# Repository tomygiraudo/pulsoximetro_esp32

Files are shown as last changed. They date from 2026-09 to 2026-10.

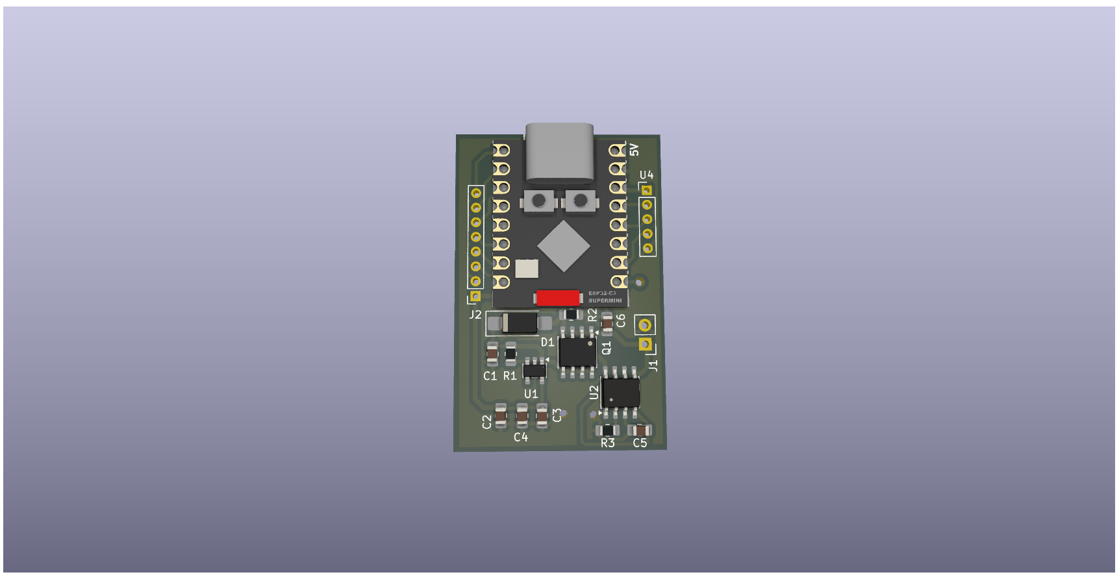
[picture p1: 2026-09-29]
PCB/Sensor_ctrl_pwr_pcb/Sensor_ctrl_pwr_pcb.png

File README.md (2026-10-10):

# Pulsoximetro portátil WI-FI

Diseño open-source de un pulsioxímetro doméstico portátil con conexión WI-FI para la materia de instrumentación Biomédica, realizado con un ESP32-C3 Super mini, un sensor de Fotoplestimografía (PPG) MAX30102, un circuito de carga y control de batería, una baterpia de 3.7 V y 230 mAh y una pantalla TFT 128x128 px con controlador STF775S.

Detalles:

- **Ciclo de medición:** el dashboard espera en "Listo para medir" hasta que el
  ESP32 manda el paquete de inicio (se presionó el botón de medición); recién
  entonces aparecen las lecturas, el cronómetro y la traza PPG.
- **Firmware** El firmware se encuentra en firmware/pulsox, tiene integrado todo lo hecho en los distintos tests de las otras carpetas.
- **Credenciales** Para que el pulsoxímetro se conecte a la aplicación y a la base de datos, se debe clonar el codigo de la base de datos y alojarlo en un proyecto firebase local. Por ultimo crear un archivo .env con las credenciales de la red wifi y las API's correspondientes para establecer la conexión con la base de datos.

## Procesamiento de Señal y diseño de filtros en Python
https://colab.research.google.com/drive/18P-XyyEuqM189sJWGMnf9TlH9UD-HeR_?usp=sharing 


Links utiles: 
https://www.analog.com/en/resources/reference-designs/maxrefdes117.html
https://www.analog.com/en/resources/technical-articles/how-to-design-a-better-pulse-oximeter.html 
https://www.analog.com/en/resources/technical-articles/guidelines-for-spo2-measurement--maxim-integrated.html

## Hardware
El esquemático del pulsioxímetro y todos sus componentes necesarios se detallan en PCB/Esquematico_V2.pdf/. Los archivos de diseño de la PCB se encuentran dentro de la misma carpeta. 



## Impresión de Carcasa
Los archivos STL para la impresión de la carcasa se encuentran en Carcasa/. Las partes fueron impresas en PETG para una mayor resistencia. 
**Parámetros de Impresión**
-  Altura de capa: 0,16 mm
-  Perímetros: 5 * 0,4 mm
-  Relleno: 50% o superior
Pulsoximetro_resorte_integrado v18
Pulsoximetro_resorte_integrado v18
Pulsoximetro_resorte_integrado v18

## Protocolo de telemetría

Ver [`PROTOCOL.md`](PROTOCOL.md): flujo de una medición (`hello` →
`measurement_start` → `telemetry` + `ppg` → fin) y formato de los mensajes JSON
que el firmware del ESP32 debe enviar por WebSocket, y el modelo de datos y las
llamadas REST del transporte en la nube. El armado de
`measurement_start`, `ppg` y `measurement_end` está marcado como **pendiente**.
El simulador (`web/js/simulator.js`) implementa el ciclo completo con un
formato provisional, así que sirve como referencia ejecutable además del
documento.

## Sistema de diseño y tipografías para pantalla y app web 

Ver [`design-system/pulsox-esp32/`](design-system/pulsox-esp32/): paleta,
tipografía, formas y especificación de componentes (gauge de SpO2, tarjeta de
frecuencia cardíaca, traza PPG, barra de navegación, historial) usados por la
web app.

 

  

## Próximos pasos

- Cerrar el armado de los paquetes pendientes de `PROTOCOL.md`
  (`measurement_start`, `ppg`, `measurement_end`).
- Firmware ESP32-C3: lectura del MAX30102, cálculo de SpO2/BPM integrado en el ESP32 C3.
- Cliente de la nube en el ESP32 (WiFi STA + TLS + login + keep-alive, integrado
  con deep sleep y el botón).
- Conectar la web app al dispositivo real y validar el modo `live` / Nube end-to-end.

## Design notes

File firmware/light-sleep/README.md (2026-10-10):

# light-sleep

Deja la placa en bajo consumo y ahí se queda. Al bootear, una sola vez:

1. **MAX30102**: corriente de los LEDs a 0 mA (`LED1_PA`/`LED2_PA` = 0) y bit
   `SHDN` en `MODE_CONFIG` (~1 µA). Se relee todo para confirmar que quedó así
   (hasta 3 intentos).
2. **ESP32-C3**: **light sleep** (`esp_light_sleep_start()`) **sin ninguna fuente
   de wakeup**, o sea indefinido. No es deep sleep: no hay timer ni botón que lo
   despierte.

El sketch nunca vuelve a encender el sensor. Como el MAX30102 se alimenta del riel
de 3V3 de la PCB (no del ESP32), queda en shutdown mientras la placa tenga
alimentación; solo se vuelve a encender si flasheás otro firmware que lo haga. Un
RESET no lo enciende: el sketch arranca de nuevo y lo vuelve a apagar.

El driver es el de [`firmware/pulsox/lib`](../pulsox/lib) (`lib_extra_dirs` en
`platformio.ini`), no una copia.

## Uso

```powershell
cd firmware/light-sleep
pio run -t upload
pio device monitor -p COM7
```

(`pio.exe` está en `%USERPROFILE%\.platformio\penv\Scripts`; el monitor sin `-p`
puede abrir un COM Bluetooth, mirá el puerto con `pio device list`.)

En el monitor tiene que salir:

```
=== light-sleep ===
MAX30102: LEDs a 0 mA y en shutdown (confirmado por lectura)
ESP32-C3: light sleep indefinido (sin fuente de wakeup). El USB se corta.
```

Si en vez de eso sale `NO se pudo apagar, err=...`, el MAX30102 no contestó por
I2C (revisar soldadura, SDA=GPIO3 / SCL=GPIO4). El ESP32 duerme igual.

## USB y volver a flashear

En light sleep el reloj del USB-Serial-JTAG del ESP32-C3 se apaga: después del
último mensaje la PC ve el puerto como desconectado y no se puede leer ni escribir
por Serial
([doc de Espressif](https://docs.espressif.com/projects/esp-idf/en/stable/esp32c3/api-guides/usb-serial-jtag-console.html)).
Por eso **para flashear otro firmware con la placa dormida** hay que:

1. Mantener apretado **BOOT** (GPIO9).
2. Tocar **RESET**.
3. Soltar BOOT y correr `pio run -t upload`.

Sin tocar BOOT: tras un RESET el puerto vive ~5 s (espera al monitor + 1,5 s) antes de
volver a dormir, que alcanza para un upload si lo lanzás en ese momento.

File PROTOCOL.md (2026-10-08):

# Protocolo de telemetría — PulsOx ESP32

Este documento define el formato de los paquetes que el firmware del ESP32-C3
debe enviar a la web app para que el dashboard funcione. Como todavía no existe
firmware, este formato es el contrato a implementar del lado del dispositivo.

> **Estado del documento.** El flujo de una medición y la semántica de cada
> paquete están definidos. El **armado de los paquetes nuevos**
> (`measurement_start`, `ppg` y `measurement_end`: campos, tipos, unidades,
> frecuencia) queda **PENDIENTE** — ver [Pendientes](#pendientes). Los paquetes
> `hello`, `telemetry` y `status` ya están cerrados.

## Transporte

**WebSocket**, con el ESP32 actuando como servidor en la red WiFi local.

```
ws://<ip-del-esp32>/ws
```

Se eligió WebSocket sobre BLE (Web Bluetooth) porque Web Bluetooth no funciona
en iOS/Safari, mientras que WebSocket sobre WiFi funciona en cualquier
navegador móvil moderno (Android e iOS) sin pairing previo. El ESP32 puede
operar en modo AP (crea su propia red `PulsOx-XXXX`) o en modo STA (se une a
la WiFi de casa) — el dashboard solo necesita la IP.

> **Transporte alternativo: la nube.** Un navegador bloquea `ws://` desde una
> página `https://` (contenido mixto), y el historial en `localStorage` no se
> comparte entre dispositivos. Por eso existe un segundo transporte en el que el
> ESP32 escribe en una Realtime Database de Firebase y la web la lee (ver
> [Transporte en la nube](#transporte-en-la-nube-firebase-realtime-database)).
> Los paquetes son los mismos y el WebSocket LAN sigue funcionando.

Todos los mensajes son JSON, un objeto por frame de texto. El campo `type`
identifica el tipo de mensaje.

## Ciclo de una medición

El dispositivo **no transmite lecturas mientras está en reposo**. Una medición
empieza cuando el usuario presiona el botón de medición del dispositivo:

```
ESP32                                                         Web app
  │  (el cliente abre la conexión)                               │
  │ ── hello ──────────────────────────────────────────────────► │  dashboard: "Listo para medir"
  │                                                              │
  │  (se presiona el botón de medición)                          │
  │ ── measurement_start ──────────────────────────────────────► │  abre la medición, arranca el cronómetro
  │ ── telemetry (≈ 1 Hz) ─────────────────────────────────────► │  SpO2, BPM, calidad, batería
  │ ── ppg (lotes de muestras) ────────────────────────────────► │  traza PPG en vivo
  │      …                                                       │
  │ ── measurement_end ────────────────────────────────────────► │  cierra la medición (ver pendientes)
```

- La web app asocia todas las lecturas recibidas entre `measurement_start` y el
  fin de la medición a **una misma medición**; el historial se agrupa así.
- `telemetry` y `ppg` solo se envían **dentro de** una medición.
- Si se cierra la conexión durante una medición, la web app la da por terminada.

## 1. `hello` — identificación del dispositivo

Se envía **una vez**, inmediatamente después de que el cliente abre la
conexión.

```json
{
  "type": "hello",
  "device_id": "pulsox-esp32-01",
  "fw_version": "0.1.0",
  "sensor": "MAX30102",
  "sample_rate_hz": 1
}
```

| Campo | Tipo | Descripción |
|---|---|---|
| `device_id` | string | Identificador único del dispositivo (p. ej. derivado de la MAC). |
| `fw_version` | string | Versión del firmware, para diagnóstico. |
| `sensor` | string | Sensor físico usado. |
| `sample_rate_hz` | number | Frecuencia aproximada de envío de `telemetry`. |

## 2. `measurement_start` — inicio de una medición

> **Estado: ⏳ PENDIENTE — armado del paquete a definir.**

Lo envía el ESP32 **una vez**, cuando se presiona el botón de medición. Es el
primer paquete de la medición: hasta que llega, la app muestra el dashboard en
espera ("Listo para medir", valores en "—", traza PPG vacía).

**Qué hace la app con este paquete:** abre una medición nueva (si había una
abierta, la cierra), pone el cronómetro en 00:00, limpia la traza PPG y crea el
grupo correspondiente en el historial.

**Supuesto provisional del cliente y del simulador** (no es el formato
definitivo): la app solo necesita el `type`. El identificador y la hora de
inicio de la medición los asigna ella misma al recibir el paquete; cualquier
otro campo se ignora. El simulador envía:

```json
{ "type": "measurement_start", "session_id": "sim-1700000000000", "uptime_ms": 5120 }
```

En el [transporte en la nube](#transporte-en-la-nube-firebase-realtime-database)
la web sintetiza este paquete con dos campos que la app **solo usa en ese
transporte**: `session_id` (la push key de `sessions/<sid>`, para que la medición
abierta coincida con el historial compartido) y `started_at` (ms epoch, para que
el cronómetro de quien se une a mitad de medición sea correcto).

## 3. `telemetry` — lectura periódica

El paquete de lecturas. Se espera aproximadamente **1 vez por segundo**, y solo
dentro de una medición (el algoritmo de SpO2/BPM del MAX30102 ya promedia
internamente sobre varios segundos de señal PPG).

```json
{
  "type": "telemetry",
  "seq": 4821,
  "uptime_ms": 182340,
  "finger_detected": true,
  "spo2": 97.4,
  "spo2_valid": true,
  "bpm": 72,
  "bpm_valid": true,
  "signal_quality": 0.86,
  "battery_pct": 78
}
```

| Campo | Tipo | Rango / notas |
|---|---|---|
| `seq` | integer | Contador incremental (detecta paquetes perdidos). |
| `uptime_ms` | integer | Milisegundos desde el boot del ESP32 (no hay RTC; el timestamp absoluto lo agrega el cliente al recibir). |
| `finger_detected` | boolean | `false` si el sensor no detecta dedo (IR por debajo de umbral). Si es `false`, `spo2`/`bpm` deben ignorarse aunque vengan presentes. |
| `spo2` | number \| null | Saturación de oxígeno en %, 0–100. `null` si no hay lectura válida. |
| `spo2_valid` | boolean | `true` solo si el algoritmo considera la lectura confiable (suficientes ciclos de pulso, sin saturación de señal). |
| `bpm` | number \| null | Frecuencia cardíaca en latidos por minuto. `null` si no hay lectura válida. |
| `bpm_valid` | boolean | Igual que `spo2_valid` pero para BPM. |
| `signal_quality` | number | 0.0–1.0, estimación de calidad de señal PPG (perfusion index normalizado o similar). Se usa para mostrar la barra de calidad de señal. |
| `battery_pct` | integer \| omitido | Opcional. Si el dispositivo no tiene medición de batería, se omite el campo por completo (no enviar `null`). |

Notas de diseño:
- Los campos `*_valid` existen porque el algoritmo de SpO2 del MAX30102 puede
  producir números incluso cuando la señal es mala; separarlos evita que el
  dashboard muestre un valor "creíble" que en realidad es ruido.
- El dashboard trata un paquete con `finger_detected: false` como "sin
  lectura": muestra "Colocá el dedo en el sensor", borra la traza PPG y no
  agrega el paquete al historial.
- Una lectura inválida aislada **no** borra el valor mostrado: la app conserva
  el último valor válido hasta 5 s (el gráfico de tendencia sí registra el
  corte).

## 4. `ppg` — señal PPG

> **Estado: ⏳ PENDIENTE — armado del paquete a definir.**

Transporta la señal fotopletismográfica **ya filtrada y acondicionada** por el
firmware, para dibujarla en vivo en el dashboard debajo de la frecuencia
cardíaca. La app **no filtra ni procesa**: solo la dibuja.

**Qué necesita la app de este paquete:**
- Muestras numéricas en orden temporal, con polaridad tal que el **pico
  sistólico apunte hacia arriba**. La escala es libre: la app autoescala el eje
  vertical, así que no hace falta normalizar ni mandar unidades.
- La frecuencia de muestreo, para ubicar cada muestra en el eje de tiempo.
- Las muestras llegan **en lotes** (un frame = varias muestras): mandar una
  muestra por frame a decenas de Hz satura el servidor WebSocket del ESP32-C3.

**Qué hace la app:** mantiene una ventana deslizante de 6 s, dibujada con un
retardo de ~0,3 s respecto de "ahora" para que los lotes se rellenen de forma
fluida. Mientras no hay dedo (según `telemetry`), no dibuja la traza.

**Supuesto provisional del cliente y del simulador** (no es el formato
definitivo): `fs` en Hz y `samples` como arreglo de números; el simulador usa
`fs = 50` y manda 10 muestras cada 200 ms.

```json
{ "type": "ppg", "fs": 50, "samples": [112, 340, 655, 801, 742, 590, 331, 40, -120, -210] }
```

## 5. `measurement_end` — fin de una medición

> **Estado: ⏳ PENDIENTE — falta decidir si existe como paquete y su armado.**

Marcaría el fin de la medición (el usuario la detiene o el firmware la corta por
duración máxima). Al recibirlo la app cierra la medición, deja de mostrar
lecturas y vuelve a "Listo para medir"; el grupo del historial queda con su
duración.

**Supuesto provisional del cliente y del simulador:** la app solo necesita el
`type`. El simulador envía `{ "type": "measurement_end", "uptime_ms": 65210 }`.

## 6. `status` — eventos y errores

Mensaje esporádico para comunicar cambios de estado que no son una lectura.

```json
{
  "type": "status",
  "level": "error",
  "code": "sensor_not_found",
  "message": "No se detecta el MAX30102 en el bus I2C"
}
```

| Campo | Tipo | Valores |
|---|---|---|
| `level` | string | `"info"` \| `"warning"` \| `"error"` |
| `code` | string | Código estable para lógica del cliente (`sensor_not_found`, `low_battery`, `wifi_reconnected`, etc.). |
| `message` | string | Texto legible, se muestra tal cual en la UI como fallback. |

## Convenciones generales

- Codificación: JSON UTF-8 en frames de texto WebSocket (no binario).
- El servidor (ESP32) puede cerrar y reabrir la conexión libremente; el
  cliente reintenta con backoff exponencial (ver `web/js/connection.js`).
- No se espera que el cliente envíe telemetría al servidor; el canal es
  unidireccional (ESP32 → navegador). Un futuro `ping`/`pong` de aplicación no
  es necesario porque el protocolo WebSocket ya tiene ping/pong nativo.
- Todos los valores numéricos van sin comillas (JSON number), nunca como
  string.
- Un `type` desconocido se descarta sin error (compatibilidad hacia adelante).

## Umbrales fisiológicos usados por el dashboard

Estos umbrales son los que la web app usa por defecto para colorear el
estado (verde / amarillo / rojo). Son guías generales de bienestar, **no**
un dispositivo médico certificado, y son configurables desde Ajustes
(se guardan en `localStorage`, no se envían al ESP32).

| Parámetro | Verde (normal) | Amarillo (precaución) | Rojo (peligro) |
|---|---|---|---|
| SpO2 | ≥ 95% | 90–94% | < 90% |
| BPM (reposo) | 60–100 | 50–59 o 101–120 | < 50 o > 120 |

## Ejemplo de sesión

Los paquetes marcados con ⏳ tienen el armado pendiente; se muestran con el
supuesto provisional del cliente.

```
→ (cliente abre ws://192.168.1.42/ws)
← {"type":"hello","device_id":"pulsox-esp32-01","fw_version":"0.1.0","sensor":"MAX30102","sample_rate_hz":1}
      … (reposo: el dashboard muestra "Listo para medir") …
      … (se presiona el botón de medición) …
← ⏳ {"type":"measurement_start"}
← {"type":"telemetry","seq":1,"uptime_ms":1000,"finger_detected":false,"spo2":null,"spo2_valid":false,"bpm":null,"bpm_valid":false,"signal_quality":0.0}
← {"type":"telemetry","seq":2,"uptime_ms":2000,"finger_detected":true,"spo2":96.8,"spo2_valid":false,"bpm":81,"bpm_valid":false,"signal_quality":0.31}
← ⏳ {"type":"ppg","fs":50,"samples":[…10 muestras…]}
← {"type":"telemetry","seq":3,"uptime_ms":3000,"finger_detected":true,"spo2":97.2,"spo2_valid":true,"bpm":74,"bpm_valid":true,"signal_quality":0.79}
← ⏳ {"type":"ppg","fs":50,"samples":[…10 muestras…]}
      …
← ⏳ {"type":"measurement_end"}
```

## Implementación de referencia (cliente)

El parseo y la validación de estos mensajes están en
[`web/js/protocol.js`](web/js/protocol.js); la traza PPG se dibuja en
[`web/js/ppg.js`](web/js/ppg.js). El simulador de demo en
[`web/js/simulator.js`](web/js/simulator.js) genera el ciclo completo
(`hello` → `measurement_start` → `telemetry` + `ppg` → `measurement_end`), así
que sirve como referencia ejecutable además de este documento. El cliente es
**permisivo** con los paquetes pendientes (solo exige el `type` y, para `ppg`,
el arreglo numérico `samples`), de modo que el armado definitivo se puede
decidir sin romper la app.

Si llegan `telemetry` o `ppg` sin un `measurement_start` previo (p. ej. el
cliente se reconecta con una medición en curso), la app abre una medición
implícita en lugar de descartar los datos.

## Transporte en la nube (Firebase Realtime Database)

Segundo transporte, para que **cualquiera con la URL de la web** vea la medición
en vivo y el historial desde cualquier red, sin conocer la IP del ESP32 ni estar
en su WiFi. GitHub Pages es hosting estático (no guarda datos ni acepta
conexiones) y el ESP32 no puede ser cliente de la *página*; lo que sí se puede es
que **los dos sean clientes del mismo servicio en la nube**:

```
ESP32 ──HTTPS (REST, con login)──►  Firebase Realtime DB  ◄──REST + streaming (EventSource), lectura pública──  Web (Pages, cualquier celular/PC)
```

- **Solo el dispositivo escribe.** La lectura es pública (sin login); la
  escritura la permite únicamente el `uid` del usuario del dispositivo
  ([`tools/cloud/database.rules.json`](tools/cloud/database.rules.json)).
- **La medición se inicia solo con el botón del dispositivo**; la app no manda
  comandos. Por eso el ESP32 puede dormir en deep sleep entre mediciones: no
  tiene que estar escuchando.
- Se guardan **valores crudos**. El estado (normal / precaución / peligro) lo
  calcula cada cliente con *sus* umbrales.
- Las horas son del servidor (`{".sv":"timestamp"}`, abreviado `SV` abajo): el
  ESP32 no tiene RTC ni necesita NTP.
- Los paquetes que entiende la app son los mismos de las secciones 1–6; este
  transporte solo cambia cómo viajan (ver [cómo lo interpreta la web](#cómo-lo-interpreta-la-web)).

### Nodos

```
/devices/<deviceId>/
  info      { device_id, fw_version, sensor, battery_pct, updated }      al arrancar y al terminar cada medición
  live      { session_id, seq, ts, elapsed_ms, finger_detected, spo2,    PUT a 1 Hz solo durante la medición;
              spo2_valid, bpm, bpm_valid, signal_quality, battery_pct,   se borra al terminar
              fs, ppg:"112,340,…" }
  sessions/<sid>  { startedAt, endedAt, readings/<pushKey> { ts, spo2, bpm, quality } }
                                                                          sid = push key (orden cronológico);
                                                                          readings: POST cada ~5 s con lectura válida
```

`<deviceId>` es la "llave" de la URL de lectura (`web/js/cloud-config.js` y
`PULSOX_DEVICE_ID`): un valor no obvio y sin datos personales.

**`live`** (se reemplaza completo con `PUT` cada segundo; la base no guarda
`null`, así que un campo sin valor **se omite**):

| Campo | Tipo | Notas |
|---|---|---|
| `session_id` | string | Push key de la sesión (`sessions/<sid>`). |
| `seq` | integer | Contador de la medición (1, 2, 3…). Cada `seq` nuevo es un "tick" para la web. |
| `ts` | number | `SV`. |
| `elapsed_ms` | integer | Milisegundos desde que se presionó el botón, medidos por el dispositivo. La web calcula con esto el inicio de la medición (quien entra a mitad ve el cronómetro correcto sin fiarse de relojes). |
| `finger_detected` | boolean | Igual que en `telemetry`. |
| `spo2`, `bpm` | number | Solo si hay dedo; ver `telemetry`. |
| `spo2_valid`, `bpm_valid` | boolean | Igual que en `telemetry`. |
| `signal_quality` | number | 0.0–1.0. |
| `battery_pct` | integer | Se omite si no se mide. |
| `fs` | integer | Frecuencia de muestreo del PPG en Hz. |
| `ppg` | string | `fs` muestras enteras (1 s de señal) separadas por comas, ya filtradas, pico sistólico hacia arriba. Se omite sin dedo. Una hoja atómica (~250 B a 50 Hz) en vez de un arreglo, y un solo request por segundo con la telemetría incluida. |

**`info`**: `device_id`, `fw_version`, `sensor` (strings, como en `hello`),
`battery_pct` (se actualiza al terminar cada medición: es la batería "en
reposo") y `updated` (`SV`).

**`sessions/<sid>`**: `startedAt` (`SV`, lo escribe el `POST` que abre la
medición), `endedAt` (`SV`, al terminar) y `readings/<pushKey>` con
`{ ts (SV), spo2, bpm, quality }` cada ~5 s mientras haya lectura válida.

### Llamadas REST del dispositivo

`<db>` es el `databaseURL` (`https://<proyecto>-default-rtdb.firebaseio.com`) y
`<auth>` el `idToken` del usuario del dispositivo (`?auth=<idToken>`). Las
escrituras que no necesitan respuesta llevan `&print=silent` (la base contesta
`204 No Content`).

| # | Cuándo | Llamada | Cuerpo | Respuesta |
|---|---|---|---|---|
| 1 | Al arrancar | `POST https://identitytoolkit.googleapis.com/v1/accounts:signInWithPassword?key=<API_KEY>` | `{"email","password","returnSecureToken":true}` | `idToken`, `refreshToken`, `expiresIn: "3600"`, `localId` |
| 2 | Antes de que venza el token | `POST https://securetoken.googleapis.com/v1/token?key=<API_KEY>` | formulario `grant_type=refresh_token&refresh_token=…` | `id_token`, `refresh_token`, `expires_in: "3600"` |
| 3 | Al arrancar | `PUT <db>/devices/<id>/info.json?auth=<auth>` | `info` completo | — |
| 4 | Al arrancar | `DELETE <db>/devices/<id>/live.json?auth=<auth>` | — | — |
| 5 | Botón de medición | `POST <db>/devices/<id>/sessions.json?auth=<auth>` | `{"startedAt": SV}` | `{"name": "<sid>"}` |
| 6 | Cada segundo | `PUT <db>/devices/<id>/live.json?auth=<auth>` | `live` completo | — |
| 7 | Cada ~5 s (lectura válida) | `POST <db>/devices/<id>/sessions/<sid>/readings.json?auth=<auth>` | `{"ts": SV, "spo2", "bpm", "quality"}` | `{"name": …}` |
| 8 | Al terminar | `PATCH <db>/devices/<id>/sessions/<sid>.json?auth=<auth>` | `{"endedAt": SV}` | — |
| 9 | Al terminar | `PATCH <db>/devices/<id>/info.json?auth=<auth>` | `{"battery_pct", "updated": SV}` | — |
| 10 | Al terminar | `DELETE <db>/devices/<id>/live.json?auth=<auth>` | — | — |

Notas para el firmware (la especificación ejecutable es
[`tools/cloud/fake_device.py`](tools/cloud/fake_device.py)):

- **Orden de cierre: 8, 9 y 10 al final.** Borrar `live` es la señal de
  "medición terminada" para los visores; si va antes, el historial que refrescan
  podría no tener todavía `endedAt`.
- **Conexión persistente.** Un handshake TLS por cada PUT de 1 Hz costaría
  ~1 s: mantener una sola conexión HTTPS abierta (keep-alive;
  `HTTPClient::setReuse(true)` en el ESP32) y reabrirla si el servidor la cierra.
- **Token.** Vence a la hora (`expiresIn: 3600`). Renovarlo con margen (p. ej. a
  los 50 min con la llamada 2); ante un `401` hacer un login nuevo (llamada 1) y
  reintentar una vez. Un `401` también lo devuelve una regla incumplida
  (`.validate`, escritura de otro usuario): la API REST responde `401
  Permission denied` ante cualquier violación de reglas.
- **Fallos de red.** Un tick que no se pudo escribir se descarta (el siguiente
  llega en 1 s); no acumular una cola. El historial se arma con las lecturas de
  la llamada 7, que no necesitan 1 Hz.
- **Arranque y deep sleep.** Al arrancar: llamadas 3 y 4 (4 limpia el `live` que
  deja un corte de energía a mitad de medición). Antes de dormir, la medición
  tiene que estar cerrada (8–10).
- **Credenciales.** Email/contraseña y API key van en un archivo que no se
  versiona (en el firmware, un header ignorado por git; en las herramientas,
  `tools/cloud/.env`). La API key web de Firebase identifica al proyecto, no
  autoriza nada por sí sola.
- **Certificado.** Validar el certificado TLS contra la CA raíz que usan los
  servidores de Google (verificarla desde el navegador antes de fijarla en el
  firmware) en lugar de `setInsecure()`.
- **Volumen.** Un PUT de `live` ronda los 0,5–0,6 KB: una medición de 1 h son
  ~2 MB de subida más ~720 lecturas de ~70 B.

### Cómo lo interpreta la web

`web/js/cloud.js` (`CloudSource`) abre un `EventSource` a
`<db>/devices/<id>/live.json` (la base manda `put` / `patch` con `{path, data}`
y un `keep-alive` cada ~30 s; si antepone un `307`, el navegador lo sigue solo),
mantiene una copia local de `live` y **sintetiza los mismos frames del
WebSocket**, de modo que `app.js` no distingue el transporte:

| Cambio en la base | Frame que recibe la app |
|---|---|
| `GET info.json` al abrir y al terminar cada medición | `hello` (`device_id`, `fw_version`, `sensor`, `sample_rate_hz: 1` y, si hay, `battery_pct`: la batería en reposo) |
| Aparece `live` o cambia su `session_id` | `measurement_start` con `session_id` y `started_at` (ms epoch = hora local de recepción − `elapsed_ms`; son los dos campos que la app usa de este paquete solo en este transporte) |
| Cada `seq` nuevo | `telemetry` y, si hay `ppg`, `ppg` (`fs` y `samples`, en ese orden) |
| `live` se borra | `measurement_end` |
| ~10 s sin un `seq` nuevo con la medición abierta | `measurement_end` (dispositivo apagado o sin WiFi a mitad); si vuelve a escribir, la medición se reabre |

Más detalles del comportamiento:

- Un `live` que ya está en la base al conectar **no se cree hasta que cambia**
  (llega otro `seq` en 3 s): si el dispositivo perdió energía a mitad de una
  medición, ese nodo queda para siempre y no debe mostrarse como una medición en
  curso. Un `live` que aparece con el stream abierto arranca sin espera.
- Sin ningún evento (ni `keep-alive`) durante 65 s se reabre el stream; ante
  `cancel` / `auth_revoked` o un error HTTP se reintenta con backoff
  (1 s … 15 s); al volver a la pestaña (`visibilitychange`; iOS corta las
  conexiones en segundo plano) se reabre y se re-sincroniza.
- Las muestras PPG llegan en lotes de 1 s: la traza se dibuja con ~1,5 s de
  demora respecto del dedo (300 ms en el transporte LAN). La pantalla TFT del
  dispositivo es inmediata.
- **Historial** (`CloudHistory`): `GET <db>/devices/<id>/sessions.json?orderBy="startedAt"&limitToLast=30`
  (requiere el `.indexOn` de las reglas). Recalcula el estado con los umbrales del
  visor y aplica el mismo adelgazado que el historial local (primera lectura,
  cada cambio de estado y una cada 20 s). Una sesión sin `endedAt` que no es la
  que se está midiendo se muestra terminada en su última lectura (no "En curso").
  Se refresca al abrir Historial, al terminar una medición y cada 10 s mientras
  haya una medición abierta con el Historial a la vista. Es de solo lectura:
  "Borrar historial" se deshabilita en esta fuente.
- La app que se sirve desde GitHub Pages (HTTPS) puede usar este transporte
  porque `fetch` / `EventSource` hacia la base también son HTTPS; el WebSocket
  LAN (`ws://`) queda bloqueado por el navegador en una página HTTPS.

### Límites y privacidad

- **Datos de salud en un servicio de lectura pública.** Para un trabajo práctico
  alcanza con un `deviceId` no obvio y sin datos personales; **no sirve como
  producto** (sin autenticación de lectores, sin borrado por el usuario).
- Plan sin costo de Firebase: 100 conexiones simultáneas (cada visor abierto es
  una) y cuotas de almacenamiento y descarga; el volumen por medición es de
  KB, pero conviene mirar el uso en la consola.
- Las reglas se verifican contra el servicio real con
  [`tools/cloud/check_rules.py`](tools/cloud/check_rules.py).

## Pendientes

Armado de los paquetes y decisiones asociadas, a cerrar junto con el firmware:

- [ ] **`measurement_start`**: campos (identificador de medición, base de
      `uptime_ms`, configuración del sensor, batería inicial, etc.).
- [ ] **`ppg`**: campos y tipos (`fs`, `seq`, `samples` como entero o float,
      timestamp/`uptime_ms` del primer sample), tamaño de lote y periodo de
      envío, polaridad y escala de la señal ya acondicionada, y verificar que el
      servidor WebSocket del ESP32-C3 sostiene el caudal.
- [ ] **Frecuencia de muestreo** de la señal PPG que se transmite (puede ser
      menor que la del ADC del MAX30102).
- [ ] **`measurement_end`**: ¿existe como paquete?, ¿lo manda el firmware al
      soltar el botón / por duración máxima / por inactividad?, ¿con motivo y
      resumen?
- [ ] **Botón presionado durante una medición**: ¿la detiene o la reinicia?
- [ ] **Sin dedo**: confirmar que durante `finger_detected: false` el firmware
      no envía `ppg` (hoy la app lo ignora después de la primera `telemetry`).
- [ ] **Reconexión a mitad de medición**: ¿`hello` informa si hay una medición
      en curso (y hace cuánto empezó) para no depender de la medición
      implícita?
- [ ] **Batería** fuera de una medición: por WebSocket hoy solo viaja en
      `telemetry`; ¿se agrega a `hello`/`measurement_start` para mostrarla en
      reposo? (En la nube ya está resuelto: `info.battery_pct`, que la web
      entrega como `hello.battery_pct`; la app lo acepta en cualquier `hello`.)
- [ ] **Cliente del ESP32 para la nube** (plan aparte): WiFi STA + TLS + login +
      keep-alive, y su integración con deep sleep y el botón (GPIO0); sigue
      [`tools/cloud/fake_device.py`](tools/cloud/fake_device.py).

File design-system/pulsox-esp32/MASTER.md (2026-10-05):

# Design System — PulsOx ESP32

> **LOGIC:** When building a specific screen, first check
> `design-system/pulsox-esp32/pages/[page-name].md`. If that file exists, its
> rules **override** this Master file. If not, follow the rules below.
>
> Rediseño "consumer wearable" (sucede al sistema teal/clínico anterior). Los
> tokens vivos están en `web/css/tokens.css`; este documento es la referencia
> de diseño detrás de ellos.

**Project:** PulsOx ESP32
**Dirección:** wearable de consumo (Apple Watch / Fitbit / Whoop): cálido,
legible, redondeado. **No** estética clínica/hospitalaria.
**Tema por defecto:** claro (día). Oscuro (noche) y Auto como opciones.

---

## Color

Dos colores de marca, cada uno ligado a una magnitud. Verde / ámbar / rojo
quedan **reservados para el estado fisiológico** y nunca se usan como decoración.

| Rol | Claro | Oscuro | Token |
|---|---|---|---|
| Fondo | `#F4F2EF` | `#0C0D12` | `--color-background` |
| Superficie (tarjetas, nav) | `#FFFFFF` | `#16181F` | `--color-surface` |
| Superficie 2 (controles) | `#ECE9E4` | `#22252F` | `--color-surface-2` |
| Pista (gauge, barras) | `#E6E3DE` | `#2A2D3A` | `--color-track` |
| Texto | `#16151D` | `#F5F4F8` | `--color-foreground` |
| Texto secundario | `#5B5A6B` | `#9EA0B4` | `--color-muted` |
| **SpO₂ / marca** (azul) | `#2B58E0` | `#6B97FF` | `--color-primary` |
| **Frecuencia / PPG** (violeta) | `#6A44D8` | `#B39BFF` | `--color-violet` |
| Destructivo | `#B93030` | `#E35B5B` | `--color-destructive` |

Contraste: texto secundario ≥ 4,5:1 sobre fondo y superficie en ambos temas; el
azul y el violeta de marca ≥ 4,5:1 sobre su superficie.

### Estado (fijo, validado, nunca tematizado)

| Estado | Valor | Token |
|---|---|---|
| Normal | `#0CA30C` | `--color-status-good` |
| Precaución | `#FAB219` | `--color-status-warning` |
| Peligro | `#D03B3B` claro / `#E35B5B` oscuro | `--color-status-critical` |

**Regla:** el estado nunca va solo en color. Siempre lleva ícono (check /
triángulo / octógono) **y** texto ("Normal" / "Precaución" / "Peligro"). El
ámbar tiene bajo contraste sobre claro, así que se usa como tinte de fondo o
color de ícono/anillo, y el texto del pill va en `--color-foreground`. Cada
estado trae un `tint` (fondo de pills y de íconos) y un `glow` (halo del anillo).

## Tipografía

**Figtree** (pesos 500 / 600 / 700 / 800) para todo. Cifras con
`font-variant-numeric: tabular-nums`.

| Uso | Tamaño / peso |
|---|---|
| Valor SpO₂ (anillo) | 66 px / 800 |
| Valor frecuencia | 52 px / 800 |
| Titular de pantalla (h1 de vista) | 30 px / 800 |
| Titular de estado (dashboard) | 26 px / 800 |
| Título de tarjeta | 16 px / 700 |
| Cuerpo / subtítulo | 14 px / 500 |
| Etiquetas, pills, controles | 12–14 px / 600–700 |

Un valor sin dato se muestra como guion "—" en `--color-muted`, peso 500 (nunca
en negrita: el guion pesado se lee como una barra).

## Forma y espaciado

- Radios: tarjetas 28 px (lista de historial 24 px), controles 16 px, botones
  grandes 18 px, **pills 999 px**.
- Espaciado entre bloques 12 px (24 px entre secciones); columna única de
  máx. 520 px con gutter de 20 px.
- Sin sombras en tarjetas: la jerarquía sale del contraste fondo/superficie. La
  única sombra es la del toast.

## Componentes

- **Pill de estado:** ícono + etiqueta, fondo = `tint` del estado, texto en
  `--color-foreground`.
- **Segmented control:** pista `--color-surface-2`, opción activa en
  `--color-primary` (selector de magnitud, tema) o en tinta (rango de tiempo).
- **Chips de filtro:** pill; activo en tinta (`--color-foreground`).
- **Switch:** 52 × 32 px, activo en `--color-primary`.
- **Campos:** 52 px de alto, fondo `--color-surface-2`, anillo de foco en
  `--color-primary`.
- **Barra de navegación inferior:** ver `pages/dashboard.md`.

## Movimiento

Transiciones de 150–400 ms con `cubic-bezier(0.4, 0, 0.2, 1)` (el gauge anima
su arco en 400 ms). `prefers-reduced-motion` desactiva transiciones y
animaciones decorativas; la traza PPG sigue desplazándose porque *es* el dato.

## Anti-patrones

- ❌ Emojis como íconos (usar SVG de trazo).
- ❌ Estado transmitido solo por color.
- ❌ Usar verde / ámbar / rojo como color decorativo o de marca.
- ❌ Animación tipo contador/odómetro en el valor principal (un signo vital en
  vivo no "carga" hasta su valor).
- ❌ Borrar o truncar el historial sin una acción explícita del usuario.
- ❌ Bloquear la UI o mostrar un spinner al reconectar: se mantiene la última
  lectura y el estado de conexión refleja el corte.
- ❌ Eje doble combinando SpO₂ y frecuencia en un mismo gráfico.
- ❌ Botones y campos de acción principal menores a 44 px (los chips y segmentados
  compactos miden 32–40 px y van siempre separados entre sí).

## Checklist previo a entregar

- [ ] Sin emojis; íconos de un mismo set de trazo
- [ ] `cursor: pointer` en todo lo clicable; foco visible (`:focus-visible`)
- [ ] Contraste de texto ≥ 4,5:1 en claro y oscuro
- [ ] `prefers-reduced-motion` respetado
- [ ] Sin scroll horizontal a 360 px, 390 px y escritorio
- [ ] Nada tapado por la barra de navegación fija (padding inferior + safe-area)
- [ ] Estados cubiertos: sin conexión, esperando medición, midiendo, sin dedo,
      calibrando, precaución, peligro

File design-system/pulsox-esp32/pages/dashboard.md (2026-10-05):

# Pantallas — Override de `MASTER.md`

> Especificación de las tres vistas de la app (Historial · Dashboard ·
> Ajustes) y de la barra de navegación. Prevalece sobre `MASTER.md` en lo que
> contradiga. Tokens, tipografía, formas y anti-patrones de Master siguen
> vigentes.

## Navegación inferior

Barra fija abajo, ancho de la columna (máx. 520 px), con tres destinos en este
orden: **Historial · Dashboard · Ajustes** (el dashboard al centro, vista por
defecto).

- Rutas por hash: `#/history`, `#/dashboard`, `#/settings`.
- Cada destino es un `<a>` de ≥ 56 px de alto con ícono (22 px) sobre etiqueta
  (12 px). El activo lleva `aria-current="page"`, ícono en `--color-primary`
  sobre una cápsula `--color-primary-tint` de 60 × 32 px, y etiqueta en negrita
  color `--color-foreground`; los inactivos van en `--color-muted`.
- Fondo `--color-surface`, filete superior `--color-line`, padding inferior con
  `env(safe-area-inset-bottom)`. El contenido reserva ese alto para que nada
  quede tapado.
- Al cambiar de vista: scroll arriba, `document.title` = "PulsOx — <vista>" y el
  foco pasa al `h1` de la vista.

## Dashboard

Entra en una sola pantalla de 390 × 844 (sin scroll), de arriba abajo:

1. **Cabecera:** marca "PulsOx" a la izquierda; a la derecha el pill de conexión
   (`En vivo` / `Conectado` / `Demo` / `Reconectando…` / `Sin conexión`, siempre
   con punto + texto) y el chip de batería (solo si el dispositivo la informa;
   `< 20 %` → ícono ámbar y "· baja").
2. **Titular de estado** (h1, 26 px) con ícono de estado, y una línea de apoyo.
   Es lenguaje natural, no una etiqueta:

   | Situación | Titular |
   |---|---|
   | Sin conexión / conectando | "Sin conexión" / "Conectando…" |
   | Conectado, sin medición | "Listo para medir" — "Presioná el botón de medición del dispositivo para empezar." |
   | Midiendo, sin dedo | "Esperando lectura" |
   | Midiendo, señal sin estabilizar | "Calibrando…" |
   | Midiendo, todo normal | "Todo en rango" |
   | Midiendo, algún valor en precaución | "Fuera del rango habitual" |
   | Midiendo, algún valor en peligro | "Valores críticos" + motivo + "Si te sentís mal, buscá atención médica." |

   Durante la medición la línea de apoyo lleva el cronómetro ("Midiendo · 00:23").
3. **Tarjeta SpO₂:** gauge de anillo abierto (270°, escala fija 80–100 %) con el
   valor en 66 px al centro y el pill de estado en el hueco inferior. El arco
   toma el color del estado, con halo suave; la pista queda en `--color-track`.
   Dos muescas marcan los umbrales de "Precaución" y "Normal" (siguen a los
   umbrales configurados).
4. **Tarjeta frecuencia cardíaca:** valor en 52 px + "lpm" y, a la derecha, el
   pill de estado.
5. **Tarjeta Señal PPG:** título + etiqueta "Filtrada" y, a la derecha, la
   calidad de señal en cinco barras (solo con dedo). Debajo, la traza en vivo:

   - Ventana de 6 s, dibujada en canvas; una línea punteada por segundo, línea
     base y rótulos "−6 s" / "ahora".
   - Trazo violeta (`--color-violet`) que se desvanece hacia la izquierda y
     alcanza su máxima intensidad en el borde vivo, con un punto en la muestra
     más reciente y un relleno suave debajo.
   - Eje vertical autoescalado y suavizado (sin unidades): la señal ya llega
     filtrada y con el pico sistólico hacia arriba.
   - Sin señal (en espera, sin dedo, sin conexión) la traza se reemplaza por una
     línea punteada y un mensaje centrado.

**Estados del valor:** sin dato → guion "—" en `--color-muted`; lectura inválida
aislada → se conserva el último valor válido hasta 5 s ("mostrar el último
estado conocido, no vaciar la pantalla"); el pill dice "Calibrando…" si pasan
más de 5 s sin lectura válida.

**Modo demo:** debajo del titular aparece un botón suave "Simular botón de
medición" / "Detener medición (demo)". En producción no existe: la medición la
inicia el botón físico del dispositivo.

## Historial

- Cabecera: h1 "Historial" y a la derecha el conteo de mediciones.
- **Tarjeta de tendencia:** segmented "SpO₂ | Frecuencia" (una magnitud por vez,
  nunca dos ejes), gráfico de línea con área degradada, bandas de zona
  (rojo / ámbar / verde según umbrales) y punto final; ticks del eje Y en los
  umbrales y cinco rótulos de tiempo repartidos por igual. Debajo, segmented de
  rango "2 min | 10 min | 1 h" en tinta.
- **Lecturas:** título de sección, chips `Todas | Precaución | Peligro` y una
  lista **agrupada por medición**. Cada grupo lleva "Hoy · 14:32" y "Medición
  de 1 min 20 s" ("En curso" si sigue abierta). Cada fila: ícono de estado en
  cuadrado tintado (40 px), "97 % SpO₂ · 72 lpm", la etiqueta del estado y la
  hora (HH:MM:SS) a la derecha. El historial anterior al agrupamiento aparece
  como "Lecturas anteriores".
- Vacío: ícono + "Todavía no hay mediciones. Iniciá una desde el dashboard." (o
  "No hay lecturas con este filtro.").

## Ajustes

Grupos en tarjetas con título en mayúsculas pequeñas: **Conexión** (dirección
WebSocket, botón "Conectar", switch "Modo demo", datos del dispositivo),
**Apariencia** (segmented **Claro** | Oscuro | Auto; Claro es el predeterminado),
**Umbrales de SpO₂**, **Umbrales de frecuencia** (campos numéricos de 52 px en
grilla de 2 columnas; sin sliders: en una lectura de salud importa la
precisión), **Historial** ("Borrar historial", destructivo, con confirmación en
un segundo toque) y el aviso de que la app no es un dispositivo médico.

## Anti-patrones específicos de estas pantallas

- ❌ Mostrar lecturas o traza PPG antes de recibir el paquete de inicio.
- ❌ Dibujar la traza PPG con el dedo fuera del sensor.
- ❌ Procesar o filtrar la señal PPG en el cliente (llega acondicionada).
- ❌ Un eje doble SpO₂ + frecuencia.
- ❌ Estado por color solo (siempre ícono + texto).
- ❌ Vaciar el valor por una única lectura inválida.

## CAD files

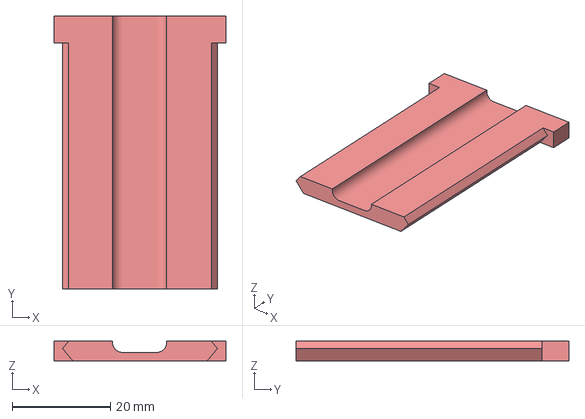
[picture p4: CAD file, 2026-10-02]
Carcasa/Tapa inferiOR.3mf
35.0 x 55.5 x 4.00 mm

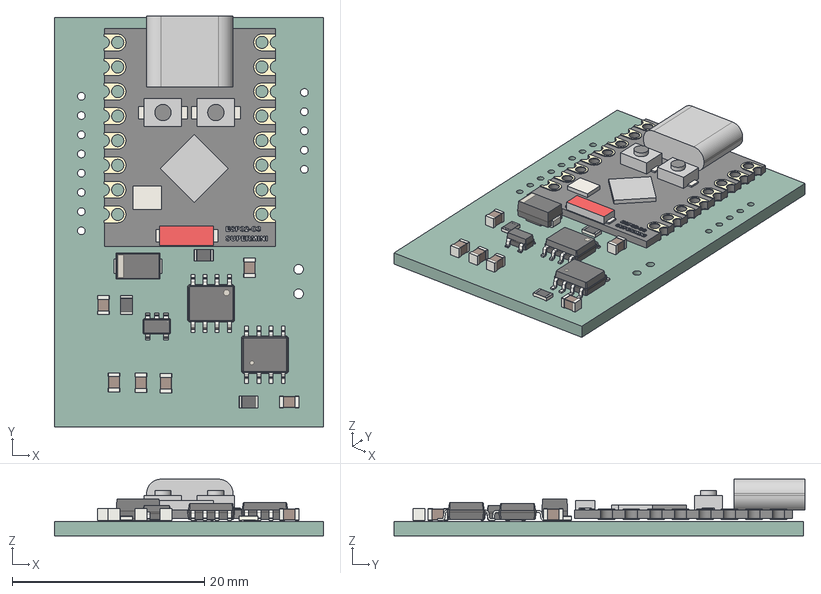
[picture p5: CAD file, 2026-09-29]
PCB/Sensor_ctrl_pwr_pcb/Sensor_ctrl_pwr_pcb.step
28.0 x 42.8 x 5.90 mm
R_0805_2012Metric x 3
SOIC-8_3.9x4.9mm_P1.27mm
C_0805_2012Metric x 6
SO-8_3.9x4.9mm_P1.27mm
SOT-23-5
D_SMA
Sensor_ctrl_pwr_pcb_PCB

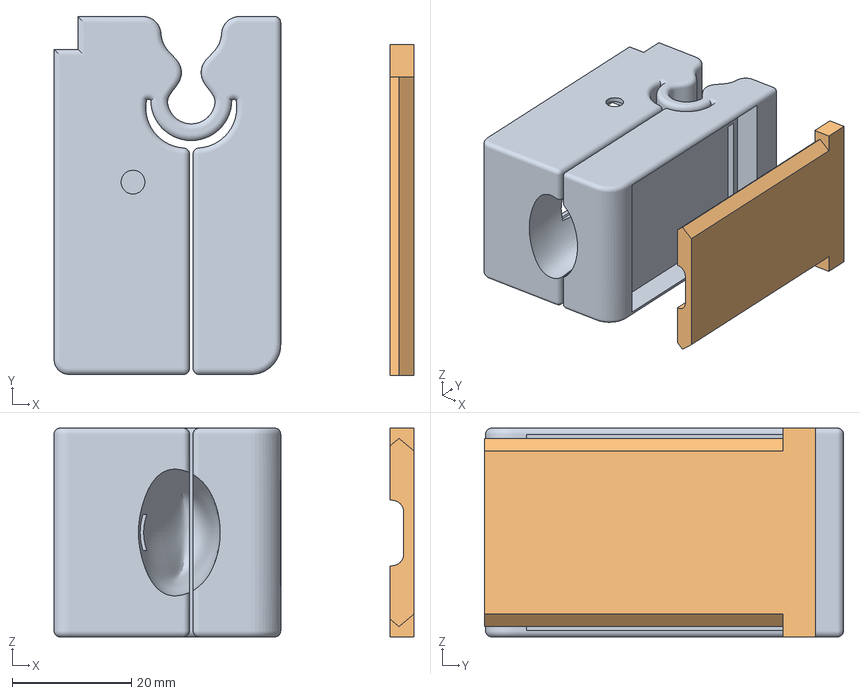
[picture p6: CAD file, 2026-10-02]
Carcasa/Pulso oxímetro.3mf
60.3 x 60.2 x 35.0 mm
Pulso oxímetro
Tapa inferiOR

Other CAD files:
PCB/Sensor_ctrl_pwr_pcb/Sensor_ctrl_pwr_pcb.obj
PCB/Sensor_ctrl_pwr_pcb/Sensor_ctrl_pwr_pcb.stl

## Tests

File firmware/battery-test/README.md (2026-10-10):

# Battery autonomy test

Sketch de prueba para el ESP32-C3 Super Mini. Un solo ciclo, en este orden:

1. **Self-test del MAX30102** (antes del WiFi): reset, prende los LEDs en modo
   SpO2, lee un par de muestras (RED/IR, válidas = distintas de 0), apaga los
   LEDs y lo deja en **shutdown** de bajo consumo. Imprime `PASS` o `FAIL`.
2. **WiFi**: conecta y manda paquetes UDP ("hello world" + su propia IP)
   durante unos segundos.
3. `deep sleep` **para siempre** (sin timer de wakeup — solo despierta de
   nuevo con un reset manual o power cycle).

El MAX30102 sigue alimentado desde el riel de 3V3 aunque el ESP32 se resetee o
esté en deep sleep, y conserva su estado (por ejemplo, LEDs prendidos desde
`peripherals-test`). Por eso se lo deja explícitamente en shutdown (bit `SHDN`,
`0x80` en `MODE_CONFIG`, registro `0x09`) por I2C (SDA=GPIO3, SCL=GPIO4, los
mismos pines que `peripherals-test`): en shutdown consume ~1 µA en vez de su
corriente de reposo normal.

No es el firmware final de PulsOx (ese va a correr un servidor WebSocket
siempre activo, ver [`PROTOCOL.md`](../../PROTOCOL.md), lo cual es
incompatible con deep sleep). Este sketch es solo para medir cuánto se
descarga la batería en reposo (deep sleep puro, sin WiFi ni wakeups
periódicos de por medio).

## Setup

1. Copiá `include/secrets.h.example` a `include/secrets.h` y completá tu
   WiFi y la IP de tu PC (`secrets.h` está en `.gitignore`, no se commitea).
2. Con PlatformIO instalado (extensión de VSCode o CLI):
   ```bash
   cd firmware/battery-test
   pio run -t upload   # flashea por USB
   pio device monitor   # opcional, para ver los logs por Serial mientras está por USB
   ```
   Si tu placa no la reconoce como `esp32-c3-devkitm-1`, probá cambiando el
   `board` en `platformio.ini` (algunos clones "Super Mini" andan mejor con
   `lolin_c3_mini`).

## Cómo correr el test

1. En tu PC, en la misma red WiFi, corré el listener para confirmar que el
   paquete llega:
   ```bash
   cd firmware/battery-test/tools
   python3 listener.py
   ```
2. Reseteá la placa (o desconectala y volvé a conectarla) y confirmá en el
   listener que llegó el `hello world from <ip>`. Después de eso la placa
   ya está dormida para siempre — no va a mandar nada más.
3. **Desconectá el USB/5V de la placa** y medí la tensión de la batería con
   el multímetro en ese instante (anotá el valor y la hora).
4. Al otro día, medí la tensión de nuevo con la placa todavía alimentada
   solo a batería (sin haberla resetear en el medio).

### Flags de debug y monitor serie

Dos flags al principio de `src/main.cpp` (también se pueden pasar con
`-D...`). Los dos vienen en **1**; para la medición real de batería ponelos en **0**:

- `MAX_TEST`: corre el self-test de LEDs/muestras al bootear. En 0 solo deja el
  sensor en shutdown.
- `DEBUG_STAY_AWAKE`: no entra en deep sleep; mantiene el USB y imprime los
  registros del sensor cada segundo, para ver que siga en shutdown después del WiFi.

En deep sleep el USB-Serial-JTAG del ESP32-C3 se apaga, la PC ve la placa como
"desenchufada" y el monitor serie se cae: **desde ahí no se puede imprimir nada**
(limitación del chip, no un bug). Además, tras un reset el USB se re-enumera y el
monitor reconecta tarde, por eso el sketch espera a que lo abras y suma 1,5 s de
margen antes de empezar.

```powershell
pio run -t upload
pio device monitor -p COM7
```

Qué mirar en el log:

- `MAX30102 self-test PASS` → los LEDs prendieron, se leyeron muestras válidas y
  quedó en shutdown (`MODE_CONFIG=0x80 LED1_PA=0x00 LED2_PA=0x00`). Si el LED
  físico sigue prendido con eso, no es el LED de medición sino un indicador del
  módulo, que no se apaga por software.
- `FAIL` indica cuál de los tres pasos falló (`LEDs on`, `samples valid`, `shutdown`).
  `I2C err=2` es un fallo genérico de la transacción (sin respuesta); `err=5`, bus trabado.

### Sobre qué esperar de la medición

El consumo en deep sleep del ESP32-C3 suele ser de **pocas decenas de µA**.
En 24h eso es un consumo de batería del orden de 0.5 mAh o menos — en una
batería LiPo típica (varios cientos de mAh) esa caída de tensión puede ser
demasiado chica para verse con un multímetro común, porque la curva de
descarga de una LiPo es bastante plana en reposo y además la tensión varía
un poco con la temperatura. Si el número que te interesa es la corriente de
deep sleep en sí (no solo "aguantó 24h sin problema"), lo más confiable es
medir **corriente** en serie entre la batería y la placa (multímetro en
rango µA/mA, o un medidor USB con esa función) en el momento en que ya está
dormida, en vez de comparar voltaje antes/después.

## Ajustar el sketch

- El payload es texto plano armado a mano: `"hello world from <ip>"`. Si
  después querés volver a mandar paquetes periódicos (para medir el ciclo
  completo wake/transmit/sleep en vez de solo el reposo), la versión
  anterior de este sketch usaba `esp_sleep_enable_timer_wakeup()` antes de
  `esp_deep_sleep_start()` — se puede volver a agregar fácil.
- `WIFI_CONNECT_TIMEOUT_MS` (10s por defecto): si no conecta en ese tiempo,
  se va a dormir igual sin mandar nada, para no gastar batería reintentando
  indefinidamente.

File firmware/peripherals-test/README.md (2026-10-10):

# Test de periféricos (MAX30102 + TFT ST7735S)

Firmware de bring-up para la PCB (`PCB/Sensor_ctrl_pwr_pcb`) con el ESP32-C3
Super Mini. **No es el firmware final de PulsOx**: solo verifica que el
sensor responda por I2C y que la pantalla responda por SPI, y después deja
corriendo una lectura en vivo del sensor.

> **Para llevar la pantalla a otro firmware, ver [TFT.md](TFT.md)**: pinout,
> configuración validada, código mínimo, qué copiar y qué no, y las lecciones
> aprendidas.

## Pines (del esquemático)

| Señal | GPIO | Uso |
|---|---|---|
| SDA-OX | 3 | I2C SDA del MAX30102 |
| SCL-OX | 4 | I2C SCL del MAX30102 |
| INT-OX | 1 | INT del MAX30102 (open-drain, activo en bajo) |
| SCK_TFT | 6 | SPI clock |
| SDA_TFT | 7 | SPI MOSI (en el ST7735S es el SDA bidireccional) |
| CS_TFT | 21 | SPI chip select |
| DATA_SEL_TFT | 10 | D/C (A0) |
| RST_TFT | 20 | Reset del TFT |
| BACKLIGHT_TFT | 5 | Backlight (pin LED del módulo) |
| SW1 | 0 | Pulsador (este test no lo usa) |

Según `PCB/Esquematico V2.pdf` / `Sensor_ctrl_pwr_pcb.kicad_sch`. Si cambiás el
esquemático, actualizá los `#define PIN_*` al principio de `src/main.cpp`.

## Setup

Con PlatformIO instalado (extensión de VSCode o CLI):

```bash
cd firmware/peripherals-test
pio run -t upload    # flashea por USB
pio device monitor   # ver el resultado de los tests por Serial
```

El Super Mini usa el USB-CDC nativo del ESP32-C3: el firmware espera hasta 4 s
a que abras el monitor antes de empezar los tests, así no te perdés el
output. Si igual se te pasó, apretá reset (o desenchufá y volvé a enchufar).

Si tu placa no la reconoce como `esp32-c3-devkitm-1`, probá con `lolin_c3_mini`
en `platformio.ini` (igual que en `battery-test`).

## Flags de compilación

Están al principio de `src/main.cpp` (cada uno se puede pisar con `-D<flag>=<n>`
en `build_flags`). Valores actuales, con la placa completa:

| Flag | Valor | Qué hace |
|---|---|---|
| `ENABLE_TFT` | `1` | Con `0` no se compila nada del TFT: no se tocan sus pines, el test 5 queda `N/D` y todo sale solo por Serial. Para probar el sensor sin pantalla conectada. |
| `TFT_USE_SOFT_SPI` | `0` | Con `1` la pantalla va por SPI por software (lento, con el init a baja velocidad). Solo para diagnóstico: separa "problema de reloj" de "problema de cableado". |
| `TFT_PIN_TEST` | `0` | `1` o `2` corren el test de soldadura del TFT en lugar de todo lo demás (ver más abajo). |
| `TFT_X_ADJUST` / `TFT_Y_ADJUST` | `-2` / `29` | Origen de la imagen en la RAM del controlador (para este módulo: columna 0, fila 32). Ver [TFT.md §3](TFT.md). |
| `TFT_INIT_TAB` | `INITR_144GREENTAB` | Variante de init de la librería de Adafruit. |
| `BL_ON` | `HIGH` | Nivel que enciende el backlight. |
| `LED_ON_LEVEL` | `LOW` | Nivel que enciende el LED integrado (GPIO8) del Super Mini. |

## Test de soldadura del TFT (`TFT_PIN_TEST`)

Con `TFT_PIN_TEST` distinto de 0 en `src/main.cpp` (o `-DTFT_PIN_TEST=n`) el
firmware **no corre ningún otro test** y maneja solo las 6 líneas de la pantalla
(J2: 1 VCC, 2 GND, 3 CS, 4 RST, 5 A0/DC, 6 SDA, 7 SCK, 8 LED). Se mide con el
multímetro contra GND, en los pines del **módulo**:

- **`1`**: las 6 líneas en 1 lógico (3.3 V) fijas. El pin que no da 3.3 V tiene
  la soldadura abierta o la pista cortada.
- **`2`**: una línea en alto por vez durante 5 s (`TFT_PIN_STEP_MS`), las otras en
  bajo, de CS a LED y repite. Si con una línea en alto otro pin también da
  tensión hay un **puente**. Las líneas usan la menor corriente de salida, así
  que con un puente los dos pines marcan un valor intermedio (~1.5–2 V) en lugar
  de 3.3 V limpio.

El Serial indica en cada paso qué pin está en alto y sus vecinos, y marca lo que
el ESP32 mismo detecta (cortos a GND o a otra línea). Volver a poner
`TFT_PIN_TEST` en `0` para usar el firmware normal.

## Qué hace

Al arrancar corre estos tests y reporta `PASS` / `FAIL` / `N/D` por Serial y en
la pantalla (esta última solo con `ENABLE_TFT 1`):

1. **I2C scan**: lista todo lo que responde en el bus y espera encontrar `0x57`.
2. **MAX PART_ID**: lee `PART_ID` (esperado `0x15`) y hace un soft reset.
3. **MAX temp die**: dispara una conversión de temperatura y la lee (valida
   escritura y lectura de registros; debería dar algo cercano a la temperatura
   ambiente + unos grados).
4. **MAX pin INT**: habilita la interrupción de fin de conversión de
   temperatura y verifica que GPIO1 esté en alto en reposo, baje con la
   interrupción, y vuelva a subir al limpiarla.
5. **LCD readback**: reset por hardware, init (`initR`) y lectura del registro
   `RDDPM` del ST7735S antes y después de la init (esperado `0x08` → `0x9C`).
   Que cambie a `0x9C` prueba que los comandos del SPI llegaron al controlador.

Después de los tests corre el **patrón visual** del TFT: pantalla completa en
rojo, verde, azul y blanco (cada una con su nombre escrito), un marco de 1 px
en el borde y un parpadeo del backlight. Al final muestra el resumen en la
pantalla durante 3 s.

### Modo en vivo

Si el MAX30102 pasó los tests 1 y 2, pasa a leer el sensor (SpO2 mode, 25
muestras/s, LEDs a ~7 mA):

- **Pantalla**: valores IR y RED, `DEDO` / `SIN DEDO` (umbral IR > 50 000) y un
  gráfico de IR autoescalado (~5 s de historia).
- **Serial**: una línea `ir:<n>,red:<n>` por muestra, para el serial plotter.

Si el MAX30102 no respondió, se queda en el resumen y reintenta detectarlo
cada 2 s: podés mover cables o retocar soldaduras sin volver a flashear.
Lo mismo si deja de responder en medio de la lectura en vivo.

## Debug: ¿está vivo el ESP32?

**LED integrado (GPIO8)**, funciona aunque el Serial no muestre nada:

| LED | Significado |
|---|---|
| 3 parpadeos rápidos al encender | El firmware arrancó |
| Fijo encendido | Dentro de `setup()` (esperando el monitor serie hasta 4 s, o corriendo tests) |
| Parpadeo rápido (4 Hz) | En `loop()`, MAX30102 sin detectar, reintentando |
| Parpadeo lento (1 Hz) | En `loop()`, leyendo el sensor en vivo |

Si no ves ni los 3 parpadeos: el ESP32 no está corriendo (modo boot, sin
alimentación, o el LED de tu placa es activo en alto → invertí `LED_ON_LEVEL`).

**Serial**: cada línea de debug es `[uptime ms][TAG] mensaje`.

- `BOOT`: causa del último reset (power-on, pin RESET, **BROWNOUT**, **CRASH**),
  si había monitor conectado, chip/heap, y marcas de `setup()` / `loop()`.
- `I2C`: nivel de SDA / SCL / INT, y en cada fallo el código crudo de
  `Wire.endTransmission()`:
  - `err=2` NACK en la dirección: nadie responde en 0x57 (alimentación,
    soldadura, dirección).
  - `err=5` timeout: SDA o SCL trabadas en bajo (corto o pull-up a 1.8 V).
- Antes de iniciar el I2C hace un **pre-check de las líneas**: con el módulo
  alimentado, SDA y SCL deben leer `1` sin pull-up interno. Distingue
  "no hay pull-up externo" de "línea sujeta en bajo".
- Mientras el sensor falta: una línea cada 2 s con el error I2C y los niveles
  SDA/SCL/INT (así, aunque abras el monitor tarde, ves el estado actual).
- En vivo: una línea por segundo con `muestras/s` (esperado ~25), IR/RED,
  punteros del FIFO y un diagnóstico (`SIN MUESTRAS NUEVAS`, `IR y RED en 0`,
  `dedo detectado` / `sin dedo`).

## Qué esperar / troubleshooting

**Serial esperado** con todo bien:

```
[PASS] I2C scan 0x57  0x57 responde (1 dispositivo/s en el bus)
[PASS] MAX PART_ID    PART_ID=0x15 REV_ID=0x..., soft reset ok
[PASS] MAX temp die   2x.xx C
[PASS] MAX pin INT    reposo alto=si, baja con int=si, flag=si, se libera=si
RDDID  = 00 00 00 (ST7735S suele dar 7C 89 F0, los clones varian)
RDDPM  = 0x00 tras reset (esperado 0x08), 0x00 tras initR (esperado 0x9C)
[N/D ] LCD readback   el modulo no devuelve datos de lectura (0x00/0x00), verificar visualmente
```

Con este módulo `LCD readback` da **`N/D`**, y es lo esperado: no devuelve datos
de lectura, así que el test de la pantalla es visual (el patrón de colores y el
marco de 1 px). Si otro módulo sí devuelve lecturas, tendría que dar `PASS` con
`RDDPM 0x08 -> 0x9C`.

| Síntoma | Causa probable |
|---|---|
| `I2C scan` no encuentra `0x57` | Soldadura de SDA/SCL, o los **pull-ups del módulo MAX30102 van a 1.8 V**: el ESP32-C3 necesita ≥ ~2.5 V para leer un "1". Muchos módulos tienen un jumper/resistencias para pasar los pull-ups a 3V3. |
| Aparece otra dirección en el scan | El módulo no es un MAX30102, o el bus tiene otro dispositivo. |
| `PART_ID` distinto de `0x15` | Módulo clon o lectura corrupta (probar bajar a 100 kHz, que ya es lo que usa el test). |
| `pin INT` falla con "reposo alto=NO" | INT en bajo desde antes: línea en corto a GND o sin pull-up. El test activa el pull-up interno del ESP32, pero el módulo tiene que dejar el pin libre. |
| `pin INT` falla con "baja con int=NO" | INT no llega a GPIO1 (pista/soldadura). |
| `LCD readback` da `N/D` | El módulo no devuelve datos de lectura (algunos no conectan el SDA al pin de salida del controlador). No es un error: **mirar la pantalla**. |
| `LCD readback` da `FAIL` con `RDDPM` igual antes y después | La lectura anda pero las escrituras no llegan: revisar SCK/SDA/CS/DC. |
| Pantalla en blanco pero el test pasa | Backlight: probar invertir `BL_ON` en `main.cpp` (si el módulo tiene transistor inversor). |
| Backlight prende pero la pantalla no dibuja nada (y `LCD readback` da `N/D`) | El backlight lo maneja GPIO5 por separado: **no** prueba el SPI. Mirar en el Serial las líneas `[TFT]` del *pin check* (cortes/puentes entre CS, DC, RST, SCK, SDA) y correr `TFT_PIN_TEST 2` midiendo con multímetro (en esta placa el culpable fue un corto entre SCK y SDA). Si el cableado está bien, probar `TFT_USE_SOFT_SPI=1`: si con SPI por software dibuja y con hardware no, es el clock del SPI (el init sale a 32 MHz y el ST7735S especifica ~15 MHz); si no dibuja en ninguno, es cableado/soldadura abierta de alguna de esas 5 líneas, o el pinout del módulo. Medir con multímetro que RST y CS estén en ~3.3 V en reposo. |
| `[E] spiAttachMISO(): SPI Does not have default pins on ESP32C3!` | Inofensivo: el módulo no tiene MISO (se pasa `-1`) y el core lo avisa. No afecta la escritura a la pantalla. |
| Los colores del patrón no coinciden con el nombre (rojo se ve azul) | Cambiar `TFT_INIT_TAB` a `INITR_BLACKTAB` en `main.cpp`. |
| Franja de ruido en un borde (p. ej. abajo) y el marco de 1 px cortado en el borde opuesto | Offset del origen de la imagen: ajustar `TFT_Y_ADJUST` / `TFT_X_ADJUST` en `main.cpp` (ruido abajo → subir `TFT_Y_ADJUST`; si empeora, usar negativo). Para este módulo quedó en X = -2, Y = +29; el offset es del módulo, no del firmware ([TFT.md §3](TFT.md)). |
| El marco de 1 px se corta en algún borde o la imagen está corrida | Offsets de columna/fila del módulo: probar otra constante de `TFT_INIT_TAB` (`INITR_144GREENTAB`, `INITR_BLACKTAB`, `INITR_GREENTAB`). |

### Notas

- El `RDDPM` se lee por bit-bang con GPIOs (el módulo no tiene MISO, la lectura
  sale por el mismo SDA): por eso el test libera el bus SPI (`SPI.end()`), lee,
  y lo vuelve a iniciar. Los valores `0x08` / `0x9C` son los del datasheet del
  ST7735; si tu clon responde otra cosa consistente, mirá el valor crudo en
  el Serial antes de darlo por fallado.
- La librería de Adafruit manda los comandos de init con el clock por defecto
  de ella (32 MHz pedidos, el ESP32-C3 baja a lo que pueda); después del
  `initR` el test lo baja a 10 MHz (`TFT_SPI_HZ`), que es más seguro para el
  dibujado. En esta placa, con las soldaduras bien, **funciona así** (SPI por
  hardware, más rápido que el de software). Si la init falla de forma
  intermitente, sospechá del cableado antes que del software.
- **GPIO21 (CS_TFT) y GPIO20 (RST_TFT)** son los pines UART0 del ESP32-C3
  (`U0TXD` / `U0RXD`). Con `USB_CDC_ON_BOOT` no se usan para el Serial, pero el
  bootloader ROM puede escribir logs por GPIO21 al arrancar, lo que mueve el
  CS del TFT unos instantes. Debería ser inofensivo porque en ese momento
  el SCK no se mueve y el test resetea y re-inicializa la pantalla; si ves
  basura en la pantalla recién al encender, es lo primero a sospechar.
- **Deep sleep**: el ESP32-C3 solo despierta por GPIO0–GPIO5. En este
  esquemático SW1 (GPIO0) y INT-OX (GPIO1) sí caen en ese rango, así que ambos
  sirven como fuente de wake-up en el firmware final.

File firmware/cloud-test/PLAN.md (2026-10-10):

# Plan: sketch de prueba `cloud-test` (ESP32-C3 → Firebase RTDB)

> **Estado (2026-10-08): implementado y compilando; falta probarlo en la placa.**
> El paso 0 (merge de `main`) y todo el código de `firmware/cloud-test/` están hechos. `pio run` compila sin warnings (RAM 12,6 %, flash 69,8 %), también con `NTP_SYNC`, `CRASH_TEST`, `FAKE_BATTERY_PCT=-1`, `SCENARIO_MIXED` y `FS_HZ=100`. En el host se comprobó que `fake_vitals` reproduce las estadísticas de `fake_device.py`, que el parser JSON lee respuestas reales de Firebase y que el `live` generado cumple `database.rules.json`.
> **Pendiente**: las pruebas 2 a 8 de "Verificación" (necesitan la placa y el `secrets.h` real; el checklist está también en el `README.md` del sketch), y confirmar con el primer handshake que cada host de Google usa la raíz indicada en "TLS con dos raíces" (esa verificación con `openssl` no se pudo repetir desde la sesión de Claude Code en la web, cuyo proxy intercepta TLS). Cuando estén hechas, este archivo se puede borrar (queda el `README.md` del sketch).
>
> Este archivo es el plan completo, escrito para retomarlo desde otra sesión de Claude Code sin el contexto de la conversación original.

## Contexto

La web ya está en GitHub Pages y lee la medición de Firebase Realtime Database (fuente "Nube"). Las reglas están verificadas contra el servicio real (18/18 PASS) y `tools/cloud/fake_device.py` (que vive en `main`, ver el paso 0) hace desde la PC lo que tiene que hacer el ESP32. Decisión del usuario: **el ESP32 es solo un cliente de la base que escribe telemetría**. No tiene servidor WebSocket, no lee nada y no recibe comandos.

El firmware de esta rama todavía no tiene HTTP/HTTPS, ni algoritmo de SpO₂/BPM, ni lectura de batería. El único código WiFi está en `firmware/battery-test` (UDP). Este plan arma un **proyecto PlatformIO de prueba aparte**, `firmware/cloud-test/`, que porta `fake_device.py` al ESP32-C3. Incluye WiFi, TLS validado contra CAs raíz, login, keep-alive, renovación del token y una medición con **valores simulados** (sin sensor ni TFT). El objetivo es validar el contrato de nube completo en el hardware real antes de integrarlo al firmware `pulsox`.

Decisiones tomadas con el usuario: ciclo simulado completo; TLS con CAs raíz, sin `setInsecure()`.

Datos del proyecto Firebase (no son secretos, ya están en `main`, `web/js/cloud-config.js`): `databaseURL = https://pulsoximetro-esp-default-rtdb.firebaseio.com`, `deviceId = pulsox-4ba0e4ea46d7`.

## Cómo ejecutarlo desde una sesión sin la placa (tablet / Claude Code en la web)

- **Se puede hacer ahí**: el paso 0, escribir todo el código y los certificados, y compilar con `pio run` si el entorno tiene PlatformIO y red para bajar el toolchain (si no, dejar la compilación para la PC). Para compilar, crear un `include/secrets.h` con valores falsos a partir del `.example`; está en `.gitignore` y **nunca** se commitea. Los certificados raíz se bajan y se verifican con `openssl`.
- **Necesita la PC con la placa por USB**: el `secrets.h` real, el flasheo y las pruebas 2 a 8 de "Verificación".
- **Nunca pegar en la sesión** la contraseña del WiFi, la API key ni la contraseña del usuario de Firebase. Esos valores se cargan después en la PC, en `secrets.h` (son los mismos de `tools/cloud/.env`).
- Al terminar: commit y push a `firmware-pulsox`. Después, en la PC: `git pull`, crear `secrets.h`, flashear y verificar.

## Paso 0: preparar la rama

- Desde la base común (`8cb9199`), `firmware-pulsox` tenía 14 commits que `main` no tiene, y `main` tiene 11 que ella no.
- **Mergear `origin/main` en `firmware-pulsox`** trae el `PROTOCOL.md` vigente (sección "Transporte en la nube"), `tools/cloud/` (`fake_device.py`, `mock_rtdb.js`, `check_rules.py`, reglas) y la web actualizada. Hoy la rama tiene un `PROTOCOL.md` viejo, solo con WebSocket.
- Solo `README.md` cambió de los dos lados, así que es el único conflicto esperable. Se resuelve conservando ambas secciones.
- Hacer el commit del merge y seguir en esa rama.

## Estructura nueva: `firmware/cloud-test/`

Sigue el molde de `firmware/battery-test/`: proyecto PlatformIO completo, README en español, `secrets.h` ignorado.

```
firmware/cloud-test/
  platformio.ini            copia del env de battery-test (esp32-c3-devkitm-1, arduino, USB-CDC); sin lib_deps
  .gitignore                .pio/  include/secrets.h
  include/secrets.h.example WIFI_SSID, WIFI_PASSWORD, FIREBASE_API_KEY, FIREBASE_EMAIL, FIREBASE_PASSWORD
  include/root_ca.h         PEM concatenado: GTS Root R1 + GTS Root R4
  src/cloud.h / cloud.cpp   WiFi + HTTPS + Auth + escrituras a la base (lo reutilizable para pulsox)
  src/fake_vitals.h / .cpp  generador de SpO2/BPM/PPG (port de Vitals de fake_device.py)
  src/main.cpp              ciclo de medición, planificador de 1 Hz, comandos por Serial, métricas
  README.md                 setup, flasheo y checklist de pruebas
```

`WiFi.h`, `WiFiClientSecure` y `HTTPClient` vienen con el core Arduino-ESP32 2.0.17 (platform espressif32, el mismo que usan los otros proyectos). No hace falta ArduinoJson: el JSON se arma con `snprintf` como en `battery-test`, y de las respuestas se extraen pocos campos con un helper mínimo.

## Diseño por archivo

### `include/root_ca.h`: TLS con dos raíces
Verificado con `openssl s_client` (2026-10-08): los hosts usan **cadenas distintas**.
- `pulsoximetro-esp-default-rtdb.firebaseio.com`: WR1 → **GTS Root R1** (RSA). El SAN incluye `*.firebaseio.com`.
- `identitytoolkit.googleapis.com` y `securetoken.googleapis.com`: WE2 → **GTS Root R4** (ECDSA).

Los dos certificados se ponen concatenados en un solo PEM y se cargan con `WiFiClientSecure::setCACert()`, que acepta varios certificados. Se bajan del repositorio oficial `pki.goog` y la huella SHA-256 (`openssl x509 -noout -fingerprint -sha256`) se verifica contra la que publica `pki.goog` y contra el almacén de certificados del sistema antes de fijarlos. No hace falta NTP: el core no valida fechas por defecto. Si el handshake fallara por la validez del certificado, se agrega `configTime()` como plan B.

### `src/cloud.h/.cpp`: cliente de la base (port de `Rest` / `Auth` / `Db` de `tools/cloud/fake_device.py:68-189`)
- `bool wifiConnect(uint32_t timeoutMs)`: `WIFI_STA`, `setAutoReconnect(true)` y un log con IP y RSSI. Sale del patrón de `firmware/battery-test/src/main.cpp:244-256`.
- La clase `CloudDb`:
  - **Conexión a la base persistente**: un `WiFiClientSecure` miembro y `HTTPClient` con `setReuse(true)`. Cada request hace `http.begin(client, DB_HOST, 443, uri, true)` y después `end()`, que deja la conexión abierta si se leyó la respuesta completa. Antes de cada request se mira `client.connected()` y se cuenta `tlsConnects` para comprobar que hay un solo handshake.
  - **Auth en una conexión aparte y efímera**: es otro host y se usa solo al arrancar y cada ~50 min.
    - `login()` hace `POST /v1/accounts:signInWithPassword?key=` y guarda `idToken`, `refreshToken`, `expiresIn` y `localId`.
    - `refresh()` hace `POST securetoken /v1/token?key=` con un formulario `grant_type=refresh_token&refresh_token=` y guarda `id_token`, `refresh_token` y `expires_in`.
    - Renueva a `expires − min(300 s, ttl/2)`, como `fake_device.py:137-152`. Si el refresh falla, hace un login nuevo.
  - `put/patch/del(path, json)` agregan `?auth=<idToken>&print=silent`. `post(path, json, String* pushKey)` extrae `"name"` de la respuesta.
  - **401 → `invalidate()` + login + un solo reintento**, como `fake_device.py:165-177`. Un `.validate` incumplido también devuelve 401, así que no se reintenta más de una vez.
  - Cada llamada devuelve el código HTTP (negativo si falla el transporte) y registra la latencia en `stats`: ok/fallas, latencia media y máxima, `tlsConnects` y `ESP.getMinFreeHeap()`.
  - Timeouts de 5 s (`setTimeout`). Un tick que falla se descarta y no hay cola, como pide `PROTOCOL.md` ("Fallos de red").
  - Helpers: `jsonEscape()` para email y contraseña, y `jsonField(body, key)` para leer un string de la respuesta. Ahí entran `idToken`, `name` y `error.message`, que se usa en los logs.
  - **Nunca se loguean el token, la contraseña ni la API key**: solo longitudes y el `uid`.

### `src/fake_vitals.h/.cpp`: port de `Vitals` y `ppg_pulse` (`fake_device.py:195-258`)
- Paseo aleatorio de SpO₂ y BPM con ruido gaussiano (Box-Muller sobre `esp_random()`).
- Escenarios `normal` y `mixed`, y unos ticks sin dedo al empezar.
- `ppgBatch()` genera `FS_HZ` enteros (1 s de señal) con el pico sistólico hacia arriba.

### `src/main.cpp`: ciclo de medición (port de `run_measurement` y `main`, `fake_device.py:268-405`)
- **Configuración** con `#ifndef`, que se puede pisar con `-D`:
  - `DB_HOST "pulsoximetro-esp-default-rtdb.firebaseio.com"`
  - `DEVICE_ID "pulsox-4ba0e4ea46d7"`
  - `FW_VERSION "cloud-test-0.1.0"`
  - `MEASUREMENT_S 60`, `CYCLES 1`, `GAP_S 10`, `FS_HZ 50`, `READING_EVERY_S 5`
  - `FAKE_BATTERY_PCT 78` (-1 la omite)
  - `SCENARIO_MIXED 0`, `CRASH_TEST 0`
  - `FORCE_REFRESH_AFTER_S 0`, para probar la renovación sin esperar 50 min.
- **Arranque**:
  1. `waitForMonitor()`, igual que en `battery-test`.
  2. WiFi.
  3. Login. Se imprime el `uid` para compararlo con el de `tools/cloud/database.rules.json:9`.
  4. `PUT info {device_id, fw_version, sensor:"MAX30102 (simulado)", battery_pct, updated:SV}`.
  5. `DELETE live`.
- **Medición**:
  - Al empezar: `POST sessions {startedAt:SV}` → `sid`.
  - Un planificador por `millis()` hace `nextTick += 1000`. Si se atrasó más de un tick, se resincroniza y se cuentan los ticks salteados.
  - En cada tick:
    - Hace `PUT live`. Lleva `session_id`, `seq`, `ts:SV`, `elapsed_ms`, `finger_detected`, `spo2`/`bpm` con sus `*_valid`, `signal_quality`, `battery_pct`, `fs` y `ppg` en CSV; `spo2`, `bpm` y `ppg` se omiten sin dedo.
    - Cada `READING_EVERY_S`, si la lectura es válida, hace `POST sessions/<sid>/readings`.
  - Con WiFi caído se saltea el request.
  - Buffer de 1 KB: el `live` ronda 0,6 KB, y la regla permite `ppg` de hasta 2000 caracteres.
- **Cierre**, en el orden de `PROTOCOL.md` (8, 9, 10): `PATCH sessions/<sid> {endedAt}` → `PATCH info {battery_pct, updated}` → `DELETE live`. Con `CRASH_TEST` se omite.
- **Al terminar los ciclos**: queda despierto y con USB, esperando comandos. Deep sleep queda fuera de esta prueba.
- **Comandos por Serial**, para probar a mano:

  | Comando | Acción |
  |---|---|
  | `m` | Nueva medición |
  | `e` | Terminar la actual |
  | `c` | Corte: deja de escribir sin cerrar |
  | `r` | Forzar la renovación del token |
  | `v` | Escritura inválida (`spo2=500`), para ver que el 401 no entra en bucle |
  | `s` | Mostrar estadísticas |

- **Logs** con el formato `DBG(tag, fmt, ...)` de `firmware/pulsox/src/debug_log.h:7-8`, copiado localmente. Cada 10 ticks se imprime un resumen con ok/total, latencia media y máxima, `tlsConnects` y el heap libre y mínimo.

### `README.md`
En el estilo de `firmware/battery-test/README.md`. Cubre:
- Copiar `secrets.h.example` a `secrets.h`. Email, contraseña y API key son los mismos de `tools/cloud/.env`.
- `pio run -t upload` y `pio device monitor`.
- Qué log esperar.
- El checklist de verificación de abajo.

## Verificación (en el hardware, en este orden)

1. **Compila**: `pio run` en `firmware/cloud-test`, revisando el uso de flash y RAM.
2. **Arranque**: conecta al WiFi (IP y RSSI). El login responde OK con el `uid` igual al de las reglas. `PUT info` y `DELETE live` devuelven 200 o 204.
3. **Medición de 60 s**: abrir `https://tomygiraudo.github.io/pulsoximetro_esp32/` en Nube. Debe pasar de "Listo para medir" a la medición en vivo (SpO₂, BPM y traza PPG). En los logs:
   - 57 o más ticks OK de 60.
   - Latencia media de `PUT` muy por debajo de 1 s.
   - **`tlsConnects` = 1**: la conexión se reutiliza.
   - Heap mínimo estable.
4. **Cierre**: el Historial muestra la sesión de ~1 min y `live` queda borrado. Se puede chequear con `curl <db>/devices/<id>/live.json` → `null`.
5. **Corte** (`c` o desenchufar): la web cierra la medición a los ~10 s. Al resetear la placa, el `DELETE live` del arranque limpia el nodo.
6. **WiFi caído**: apagar el hotspot ~20 s a mitad de la medición. Los ticks fallan sin colgar la placa y se reanudan solos. La web cierra la medición y la reabre.
7. **Token**: con `-DFORCE_REFRESH_AFTER_S=60` o el comando `r` debe aparecer "token renovado" y los `PUT` siguientes deben dar OK. Si se puede, una corrida de más de 60 min confirma la renovación natural y que el heap no pierde memoria.
8. **Regla incumplida** (`v`): 401 → login nuevo → reintento → 401 → tick descartado. El siguiente tick da OK y no hay bucle.

## Fuera de alcance (pendientes que encontró la exploración)

- **Sensor real y algoritmo de SpO₂/BPM**: no existen todavía. En `firmware/pulsox/include/config.h:34-84` solo están los parámetros. La integración se hace después, reemplazando `fake_vitals` por el pipeline real.
- **Batería**: la PCB no cablea ningún ADC a la batería. GPIO2, GPIO8 y GPIO9 están libres, y `CHARGING`/`COMPLETE` del TP4056 no llegan al ESP32. El firmware real tendrá que omitir `battery_pct` o agregar un divisor (decisión de hardware).
- **Botón GPIO0 y deep sleep**: ningún código usa el botón y `pulsox` no duerme. El ciclo "botón → medición → cierre → dormir" va en el plan de integración.
- **Limpieza de docs**: quitar el WebSocket/"Red local" de `PROTOCOL.md`, del README y de la app (por ejemplo `firmware/battery-test/README.md:19-23`, que menciona el servidor WebSocket), según la decisión de que el ESP32 sea solo cliente.
- Ruta contra el mock local por `http://`: no hace falta, la base real ya está verificada.

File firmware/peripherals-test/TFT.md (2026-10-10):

# Pantalla TFT ST7735S 128×128: guía de integración

Referencia para llevar la pantalla a otro firmware (por ejemplo `firmware/pulsox`).
La secuencia de init y los valores de esta guía están **validados en hardware**
(PCB V2 + ESP32-C3 Super Mini, 2026-10-07): SPI por hardware, patrón visual
completo y gráfico en vivo funcionando. El código de referencia es
[`src/main.cpp`](src/main.cpp) de este proyecto; el diagnóstico paso a paso está
en el [README](README.md).

> **Librería lista para usar:**
> [`firmware/pulsox/lib/tft_st7735/tft_st7735.h`](../pulsox/lib/tft_st7735/tft_st7735.h).
> Es un único `.h` con toda la configuración de esta guía, la secuencia de init,
> funciones de texto y de gráfico de señal, y un instructivo para armar pantallas
> (comentado en español). Para `firmware/pulsox` conviene usarla en lugar de
> copiar el bloque de §4. La secuencia de init y los ajustes son los validados
> acá; `tftPrintAt` y `TftTrace` compilan pero todavía no se probaron en la placa.

## 1. Resumen

| | |
|---|---|
| Módulo | TFT 1.44" 128×128, controlador ST7735S, 8 pines |
| Bus | SPI por hardware, **solo escritura** (el módulo no tiene MISO) |
| Librerías | `Adafruit GFX Library` 1.12.6 + `Adafruit ST7735 and ST7789 Library` 1.11.0 (trae `Adafruit BusIO` 1.17.4) |
| Plataforma | PlatformIO `espressif32` 7.0.1, framework Arduino-ESP32 2.0.17, placa `esp32-c3-devkitm-1` |
| Init | `initR(INITR_144GREENTAB)` |
| Origen de la imagen | desplazado con `nudgeOrigin(-2, +29)` (ver §3) |

Los números de versión son los que estaban instalados cuando se validó. En el
`platformio.ini` las librerías están con `^` y la plataforma sin fijar: si algo
cambia al actualizar, fijá estas versiones.

## 2. Hardware

Pinout del conector **J2** de la PCB (según `Esquematico V2.pdf` /
`Sensor_ctrl_pwr_pcb.kicad_sch`). El módulo tiene que tener el mismo orden:
`VCC GND CS RESET A0 SDA SCK LED`.

| J2 | Señal del módulo | Señal PCB | GPIO | Notas |
|---|---|---|---|---|
| 1 | VCC | +3V3 | | 3.3 V, no sale de un GPIO |
| 2 | GND | GND | | |
| 3 | CS | CS_TFT | **21** | CS manejado por software por la librería |
| 4 | RESET | RST_TFT | **20** | la librería hace el reset por hardware en `initR()` |
| 5 | A0 (DC) | DATA_SEL_TFT | **10** | |
| 6 | SDA (MOSI) | SDA_TFT | **7** | MOSI del SPI |
| 7 | SCK | SCK_TFT | **6** | clock del SPI |
| 8 | LED | BACKLIGHT_TFT | **5** | backlight, **activo en alto** |

- **GPIO20/21 son los pines UART0** del ESP32-C3. Con `-DARDUINO_USB_CDC_ON_BOOT=1`
  el Serial va por USB y no los usa, pero el bootloader ROM puede escribir por
  GPIO21 (CS) al arrancar. Durante las pruebas no se reportó basura en la pantalla
  al encender; si aparece, es lo primero a sospechar.
- Ninguno de estos pines choca con los de `firmware/pulsox/include/config.h`
  (I2C en 3/4, INT en 1, LED en 8).
- GPIO5 y GPIO1 pueden despertar de deep sleep, GPIO6/7/10/20/21 no. No importa
  para el SPI, sí para decidir qué hacer con el backlight al dormir (§7).

## 3. Configuración validada

| Parámetro | Valor | Por qué |
|---|---|---|
| `SPI.begin(sck, miso, mosi, ss)` | `(6, -1, 7, -1)` | sin MISO ni CS por hardware |
| Reloj durante `initR()` | 32 MHz (default fijo de la librería) | funciona en esta placa |
| `setSPISpeed()` | `10000000` (10 MHz), **después** de `initR()` | `initR()` pisa cualquier velocidad anterior |
| `setRotation()` | `0` | |
| `nudgeOrigin(dx, dy)` | `(-2, +29)`, **después** de `setRotation()` | ver abajo |
| Backlight | GPIO5 en `HIGH` | |

**Por qué `nudgeOrigin(-2, +29)`.** El ST7735 tiene una RAM más grande que la
pantalla visible y la librería asume dónde empieza la parte visible. Para
`INITR_144GREENTAB` en rotación 0 asume la columna 2 y la fila 3. Este módulo
muestra la ventana en la **columna 0, fila 32** (`2-2 = 0`, `3+29 = 32`); con los
valores por defecto quedaba una franja de ruido abajo, que era RAM sin escribir.
Es un dato **del módulo, no del firmware**: si cambiás de módulo hay que
recalibrarlo (ver §6.4).

`nudgeOrigin` es una subclase mínima porque `_xstart` / `_ystart` son miembros
protegidos de la librería y `setRotation()` los recalcula, así que el ajuste va
siempre después.

## 4. Cómo integrarlo en otro firmware

1. **`platformio.ini`**:
   ```ini
   lib_deps =
       adafruit/Adafruit GFX Library@^1.12.6
       adafruit/Adafruit ST7735 and ST7789 Library@^1.11.0
   ```
2. **Pines y ajustes** en el `config.h` del firmware destino (misma tabla que §2 y §3).
3. **Código mínimo.** Este bloque compila tal cual en un proyecto con la
   configuración de este README (flash 252 KB, RAM 14 KB, sin warnings) y repite
   la secuencia validada de `testLcd()`:

   ```cpp
   #include <Arduino.h>
   #include <SPI.h>
   #include <Adafruit_GFX.h>
   #include <Adafruit_ST7735.h>

   // Pins (PCB/Sensor_ctrl_pwr_pcb, Esquematico V2)
   #define PIN_SCK_TFT 6   // SPI clock
   #define PIN_SDA_TFT 7   // SPI MOSI (the module's SDA)
   #define PIN_CS_TFT 21
   #define PIN_DC_TFT 10   // A0
   #define PIN_RST_TFT 20
   #define PIN_BL_TFT 5    // backlight (LED pin), active high

   #define TFT_W 128
   #define TFT_H 128
   #define TFT_INIT_TAB INITR_144GREENTAB
   #define TFT_SPI_HZ 10000000
   #define TFT_X_ADJUST -2   // effective origin in controller RAM = (0, 32)
   #define TFT_Y_ADJUST 29

   // Adafruit_ST7735 plus a way to move the image origin (the offsets are protected).
   class TftPanel : public Adafruit_ST7735 {
    public:
     using Adafruit_ST7735::Adafruit_ST7735;
     // Call AFTER setRotation(), which recomputes the origin from the library's offsets.
     void nudgeOrigin(int8_t dx, int8_t dy) {
       _xstart += dx;
       _ystart += dy;
     }
   };

   static TftPanel tft(&SPI, PIN_CS_TFT, PIN_DC_TFT, PIN_RST_TFT);

   static void tftBegin() {
     pinMode(PIN_BL_TFT, OUTPUT);
     digitalWrite(PIN_BL_TFT, HIGH);
     SPI.begin(PIN_SCK_TFT, -1, PIN_SDA_TFT, -1);  // no MISO, no hardware CS
     tft.initR(TFT_INIT_TAB);                      // init commands go out at 32 MHz
     tft.setSPISpeed(TFT_SPI_HZ);                  // drawing at 10 MHz
     tft.setRotation(0);
     tft.nudgeOrigin(TFT_X_ADJUST, TFT_Y_ADJUST);
     tft.fillScreen(ST77XX_BLACK);
   }

   void setup() {
     tftBegin();
     tft.drawRect(0, 0, TFT_W, TFT_H, ST77XX_WHITE);   // 1 px frame: all 4 edges must show
     tft.setTextColor(ST77XX_WHITE, ST77XX_BLACK);
     tft.setTextSize(2);
     tft.setCursor(8, 8);
     tft.print("PulsOx");
   }

   void loop() {
     static uint32_t n = 0;
     tft.setCursor(8, 40);
     tft.printf("%lu   ", (unsigned long)n++);
     delay(100);
   }
   ```
   Compilar no es lo mismo que probarlo: este bloque en sí no se flasheó, pero
   cada llamada y su orden son los de `testLcd()`, que sí corre en la placa.
4. **Para un firmware con sensor en tiempo real** (como `firmware/pulsox`, que
   lee el FIFO del MAX30102 cada 10 ms y el FIFO guarda 320 ms de datos):
   - **Usá SPI por hardware.** El SPI por software es demasiado lento para esto
     (estimado: una pantalla completa lleva del orden de medio segundo, más que
     el FIFO; no se midió, pero con SPI por hardware refrescó claramente más
     rápido).
   - **Dibujá solo lo que cambia.** Para texto, `setTextColor(fg, bg)` con fondo
     opaco repinta sin borrar antes y no parpadea. Para gráficos, dibujá en un
     `GFXcanvas16` fuera de pantalla y mandalo de una con `drawRGBBitmap()`, como
     hace `drawLive()` (el canvas de 128×72 ocupa 18 KB de RAM).
   - **Presupuesto de tiempo** (cálculo teórico a 10 MHz y 16 bits por píxel, no
     medido): 128×72 px ≈ 15 ms, pantalla completa ≈ 26 ms. Dibujar cada 100 ms
     (`LIVE_REFRESH_MS`) deja margen de sobra respecto de los 320 ms del FIFO.
     Las transferencias bloquean: no las hagas desde una interrupción.

## 5. Qué NO copiar

Esto existe solo para el bring-up, no hace falta en el firmware final:

- **La lectura por bit-bang de `RDDID` / `RDDPM`** (`tftReadReg`) y el
  `SPI.end()` / `SPI.begin()` de `testLcd()`. Este módulo no devuelve datos de
  lectura (siempre `0x00`), así que `LCD readback` queda en `N/D` y la
  verificación es visual.
- **`tftPinCheck()`, `TFT_PIN_TEST` y `TFT_USE_SOFT_SPI`**: herramientas para
  diagnosticar una PCB nueva (ver §6 y el README).
- **`visualPattern()`**: opcional. Es útil para validar un módulo nuevo.
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

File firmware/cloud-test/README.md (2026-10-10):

# Cloud test (ESP32-C3 → Firebase Realtime Database)

Sketch de prueba para el ESP32-C3 Super Mini. Hace desde la placa lo mismo que
[`tools/cloud/fake_device.py`](../../tools/cloud/fake_device.py) hace desde la
PC: una medición **con valores simulados** (sin sensor ni TFT) escrita por REST
a la base, para validar el contrato de nube de
[`PROTOCOL.md`](../../PROTOCOL.md) ("Transporte en la nube") en el hardware real
antes de integrarlo al firmware `pulsox`.
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

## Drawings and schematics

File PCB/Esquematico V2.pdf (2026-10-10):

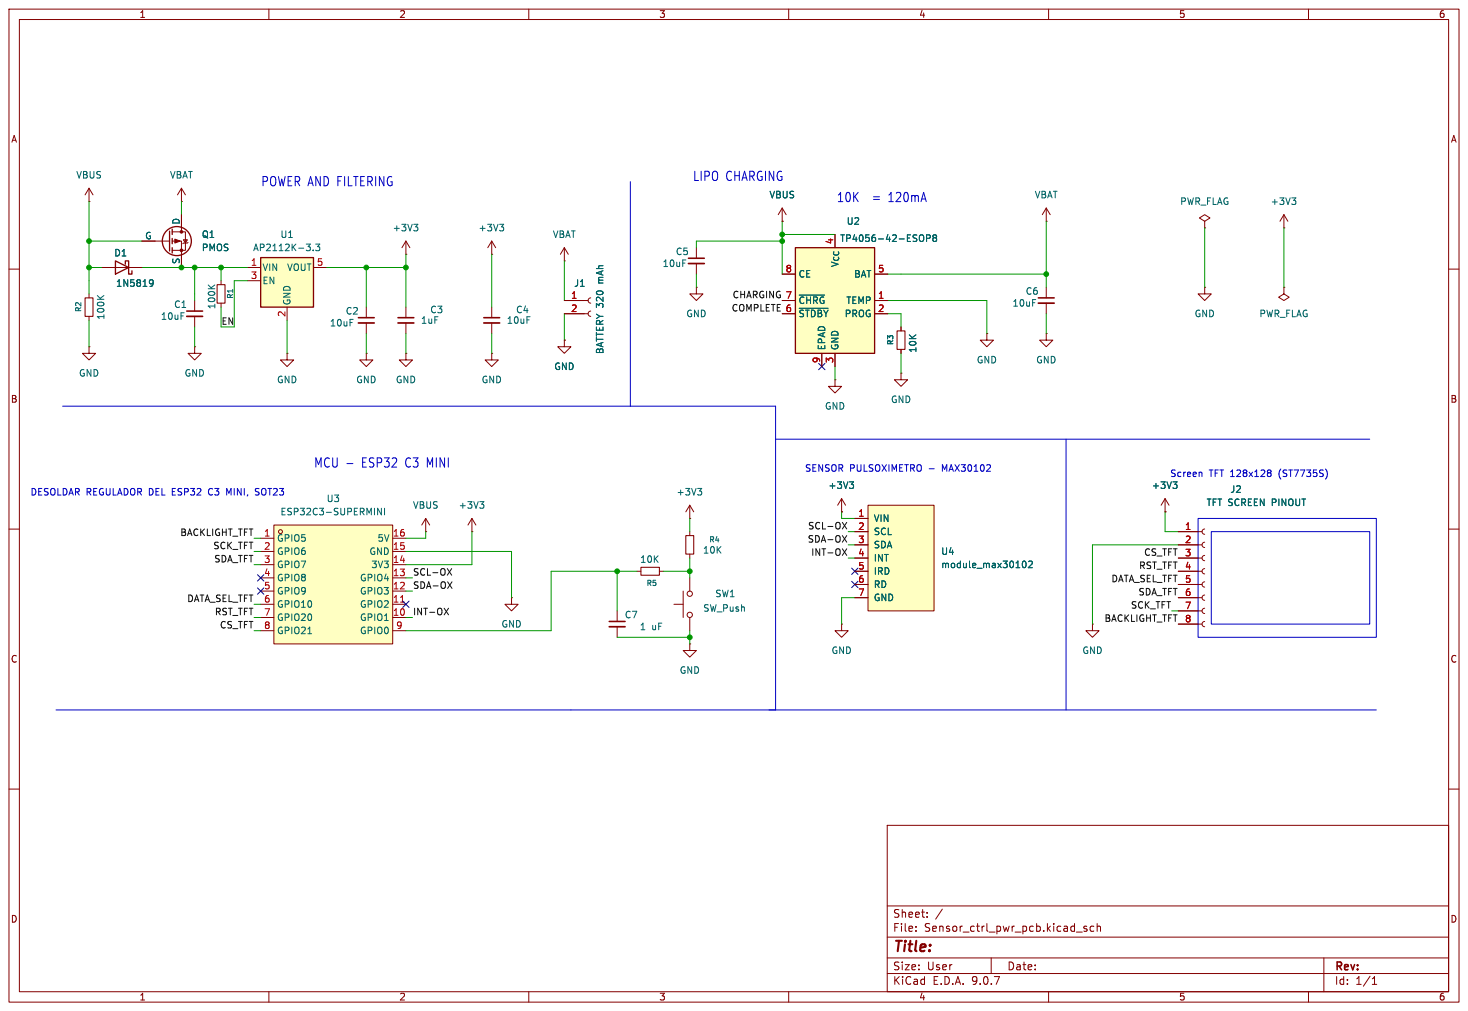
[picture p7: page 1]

3 BAT 5 TEMP 1 PROG 2 U2 TP4056-42-ESOP8 GND

J1 BATTERY 320 mAh VBAT GND GND
J1 BATTERY 320 mAh
2 GND

J2 TFT SCREEN PINOUT GND

Id: 1/1 Title: File: Sensor_ctrl_pwr_pcb.kicad_sch Sheet: /

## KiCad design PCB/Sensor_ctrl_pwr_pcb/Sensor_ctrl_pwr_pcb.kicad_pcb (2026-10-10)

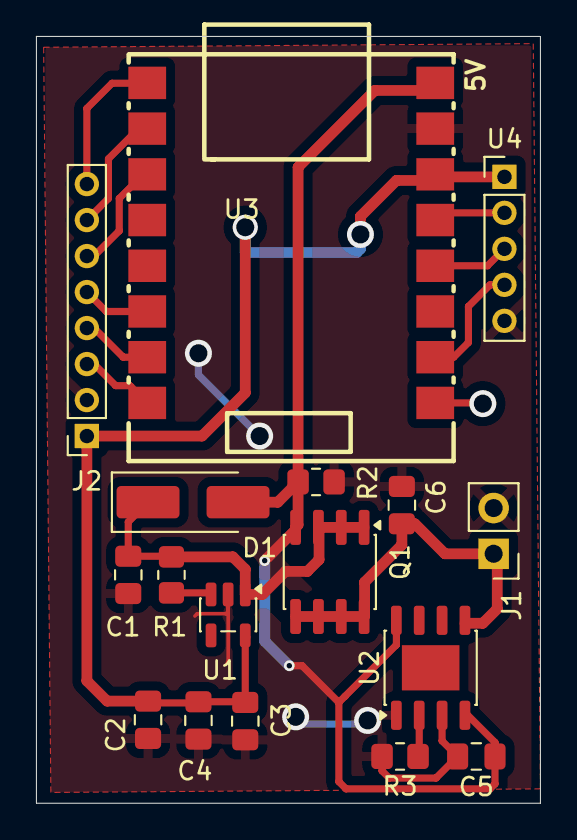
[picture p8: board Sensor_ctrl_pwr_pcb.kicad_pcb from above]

Board: 2 copper layers, 28.0 x 42.6 mm, 17 parts (0 on the bottom side), 16 nets.

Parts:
C1, C2, C4, C5, C6: 10uF; C_0805_2012Metric_Pad1.18x1.45mm_HandSolder
C3: 1uF; C_0805_2012Metric_Pad1.18x1.45mm_HandSolder
D1: 1N5819; D_SMA_Handsoldering
J1: BATTERY 320 mAh; PinHeader_1x02_P2.54mm_Vertical
J2: TFT SCREEN PINOUT; PinSocket_1x08_P2.00mm_Vertical
Q1: PMOS; SOIC-8_3.9x4.9mm_P1.27mm
R1, R2: 100K; R_0805_2012Metric_Pad1.20x1.40mm_HandSolder
R3: 10K; R_0805_2012Metric_Pad1.20x1.40mm_HandSolder
U1: AP2112K-3.3; SOT-23-5
U2: TP4056-42-ESOP8; SOIC-8-1EP_3.9x4.9mm_P1.27mm_EP2.514x3.2mm
U3: ESP32C3-SUPERMINI; COMM-SMD_16P-L22.5-W18.0-P2.54-TL
U4: module_max30102; PinHeader_1x05_P2.00mm_Vertical

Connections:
+3V3: C2.1, C3.1, C4.1, J2.1, U1.5 (VOUT), U3.14 (3V3), U4.1 (VIN)
/BACKLIGHT_TFT: J2.8, U3.1 (GPIO5)
/CS_TFT: J2.3, U3.8 (GPIO21)
/DATA_SEL_TFT: J2.5, U3.6 (GPIO10)
/EN: R1.2, U1.3 (EN)
/INT-OX: U3.10 (GPIO1), U4.4 (INT)
/RST_TFT: J2.4, U3.7 (GPIO20)
/SCK_TFT: J2.7, U3.2 (GPIO6)
/SCL-OX: U3.13 (GPIO4), U4.2 (SCL)
/SDA-OX: U3.12 (GPIO3), U4.3 (SDA)
/SDA_TFT: J2.6, U3.3 (GPIO7)
GND: C1.2, C2.2, C3.2, C4.2, C5.2, C6.2, J1.2, J2.2, R2.2, R3.2, U1.2 (GND), U2.1 (TEMP), U2.3 (GND), U3.15 (GND), U4.5 (IRD)
unnamed: C1.1, D1.1 (K), Q1.1 (D), Q1.2 (G), Q1.3 (S), R1.1, U1.1 (VIN)
unnamed: R3.1, U2.2 (PROG)
VBAT: C6.1, J1.1, Q1.5, Q1.6, Q1.7, Q1.8, U2.5 (BAT)
VBUS: C5.1, D1.2 (A), Q1.4, R2.1, U2.4 (V_{CC}), U2.8 (CE), U3.16 (5V)

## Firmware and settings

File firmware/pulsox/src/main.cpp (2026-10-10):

// PulsOx firmware entry point. Orchestration only: the sensor driver lives in
// lib/max30102, the signal processing in lib/ppg, the screens in src/display.cpp.
//
// Current stage: sensor -> signal processing -> TFT, no WiFi. Starts the MAX30102
// at 100 samples/s, feeds every sample to the pipeline (finger, filters, SpO2,
// heart rate), shows the result and the pulse trace on the TFT and prints one line
// per second with the result and the sensor health (samples/s, last RED/IR, FIFO
// overflows, slowest screen update). In CSV mode (send 'c') it also streams every
// sample with its filtered values, and the result, for tools/capture.py and
// tools/validate_ppg.py.
#include <Arduino.h>
#include <Wire.h>
#include "config.h"
#include "debug_log.h"
#include "display.h"
#include "i2c_diag.h"
#include "max30102.h"
#include "ppg_processor.h"
#include "serial_stream.h"
#include "status_led.h"

static Max30102 sensor;
static PpgProcessor ppg;
static const Max30102Config SENSOR_CFG = {SENSOR_FIFO_CONFIG, SENSOR_SPO2_CONFIG,
                                          SENSOR_LED_RED_PA, SENSOR_LED_IR_PA};

static bool streaming = false;
static uint8_t i2cFails = 0;

static uint32_t sampleIndex = 0;     // samples since the sensor was started
static uint32_t lastOverflow = 0;
static PpgSample lastSample = {0, 0};
static uint16_t samplesInWindow = 0;
static uint32_t statsAt = 0;

static bool fingerShown = false;  // what the screen says: measuring (true) or "no finger"
static uint32_t displayWorstUs = 0;  // slowest displayUpdate() since the last LIVE line

// The sensor was (re)started or lost: nothing to measure, so the "no finger" screen. It is
// the only error screen the design has; it also covers a missing sensor.
static void showNoFinger() {
  fingerShown = false;
  displaySetNoFinger();
}

// Every sample, right after ppg_push(). The screen follows the finger sample by sample
// (the pipeline only refreshes its result once per second) and draws the trace of the IR
// through the wide display filter (ir_view), which has the heartbeat pointing up and keeps
// the dicrotic notch that the measuring filter removes.
static void feedDisplay(const PpgDebug &d) {
  if (d.finger != fingerShown) {
    fingerShown = d.finger;
    if (fingerShown) {
      displaySetMeasuring(0, 0);  // "--" until the first valid values
    } else {
      displaySetNoFinger();
    }
  }
  if (fingerShown) displayPushPpg(d.ir_view);
}

// Once per second, with the pipeline result. Invalid values show as "--".
static void showResult(const PpgOutput &o) {
  if (!fingerShown) return;  // the result may still describe the finger that was just removed
  displaySetMeasuring(o.spo2_valid ? (int)(o.spo2 + 0.5f) : 0, o.bpm_valid ? (int)(o.bpm + 0.5f) : 0);
}

static void updateDisplay() {
  uint32_t t0 = micros();
  displayUpdate();
  uint32_t dt = micros() - t0;
  if (dt > displayWorstUs) displayWorstUs = dt;
}

static bool startSensor() {
  static bool diagnosed = false;  // run the I2C diagnosis once per failure streak, not on every retry
  if (!sensor.begin(Wire)) {
    DBG("MAX", "no se pudo iniciar el MAX30102: err=%u (%s)", sensor.lastError(),
        Max30102::errorText(sensor.lastError()));
    if (!diagnosed) {
      diagnosed = true;
      i2cDiagnose();
    }
    return false;
  }
  diagnosed = false;
  if (!sensor.configure(SENSOR_CFG)) {
    DBG("MAX", "no se pudo configurar el MAX30102: err=%u (%s)", sensor.lastError(),
        Max30102::errorText(sensor.lastError()));
    return false;
  }
  i2cFails = 0;
  sampleIndex = 0;
  lastOverflow = 0;
  samplesInWindow = 0;
  ppg_init(&ppg);
  showNoFinger();
  statsAt = millis();
  DBG("MAX", "sensor configurado: %.0f muestras/s, LEDs RED=0x%02X IR=0x%02X", SENSOR_FS_HZ,
      SENSOR_LED_RED_PA, SENSOR_LED_IR_PA);
  return true;
}

// The once-per-second result of the pipeline, as a log line.
static void printResult(const PpgOutput &o) {
  if (!o.finger) {
    DBG("PPG", "sin dedo");
    return;
  }
  char spo2[8] = "--", bpm[8] = "--";
  if (o.spo2_valid) snprintf(spo2, sizeof(spo2), "%.0f", o.spo2);
  if (o.bpm_valid) snprintf(bpm, sizeof(bpm), "%.0f", o.bpm);
  DBG("PPG", "SpO2=%s%% BPM=%s | R=%.3f PI=%.2f%%%s", spo2, bpm, o.r_ratio, o.perfusion_index,
      o.saturated ? " | SATURADO" : "");
}

static void pollSensor() {
  PpgSample buf[32];
  int n = sensor.readFifo(buf, sizeof(buf) / sizeof(buf[0]));
  if (n < 0) {
    i2cFails++;
    if (i2cFails == 1) {  // log only the first failure of a streak
      DBG("I2C", "fallo al leer el FIFO: err=%u (%s)", sensor.lastError(),
          Max30102::errorText(sensor.lastError()));
    }
    return;
  }
  i2cFails = 0;

  uint32_t overflow = sensor.overflowCount();
  if (overflow != lastOverflow) {
    lastOverflow = overflow;
    streamEvent(sampleIndex, "fifo_overflow", overflow);
    DBG("MAX", "el FIFO desbordo: %lu muestras perdidas en total", (unsigned long)overflow);
  }

  for (int i = 0; i < n; i++) {
    bool refreshed = ppg_push(&ppg, buf[i].red, buf[i].ir);
    streamSample(sampleIndex, buf[i], *ppg_debug(&ppg));
    feedDisplay(*ppg_debug(&ppg));
    if (refreshed) {
      streamResult(sampleIndex, *ppg_output(&ppg));
      printResult(*ppg_output(&ppg));
      showResult(*ppg_output(&ppg));
    }
    sampleIndex++;
    lastSample = buf[i];
  }
  samplesInWindow += n;
}

static void printStats() {
  if (millis() - statsAt < STATS_PERIOD_MS) return;
  statsAt += STATS_PERIOD_MS;
  DBG("LIVE", "%u muestras/s | red=%lu ir=%lu | overflows=%lu | fallos I2C=%u | pantalla max %lu us",
      samplesInWindow, (unsigned long)lastSample.red, (unsigned long)lastSample.ir,
      (unsigned long)sensor.overflowCount(), i2cFails, (unsigned long)displayWorstUs);
  samplesInWindow = 0;
  displayWorstUs = 0;
}

void setup() {
  statusLedBegin();

  Serial.begin(115200);
  uint32_t start = millis();
  while (!Serial && millis() - start < SERIAL_WAIT_MS) delay(10);  // USB-CDC: wait for the monitor
  delay(300);
  streamBegin();

  Serial.println();
  Serial.println("=== PulsOx firmware ===");
  printBootInfo();

  if (displayBegin()) {
    displaySetStatus(false, BATTERY_PLACEHOLDER_PCT);
    DBG("BOOT", "pantalla lista (buffer de 32 KB)");
  } else {
    DBG("BOOT", "no hay RAM para el buffer de la pantalla (32 KB): sigue sin pantalla");
  }

  pinMode(PIN_INT_OX, INPUT_PULLUP);
  i2cPreCheck();
  Wire.begin(PIN_SDA_OX, PIN_SCL_OX);
  Wire.setClock(I2C_CLOCK_HZ);

  streaming = startSensor();
  if (!streaming) DBG("BOOT", "sin sensor: reintento cada %d ms", SENSOR_RETRY_MS);
}

void loop() {
  statusLedUpdate(streaming);
  streamPollCommands();
  updateDisplay();  // also while the sensor is missing: the "no finger" icon is animated

  if (!streaming) {
    static uint32_t lastTry = 0;
    if (millis() - lastTry < SENSOR_RETRY_MS) return;
    lastTry = millis();
    streaming = startSensor();
    return;
  }

  pollSensor();
  if (i2cFails >= I2C_FAILS_BEFORE_LOST) {
    DBG("I2C", "el MAX30102 dejo de responder (%u fallos seguidos), reintentando", i2cFails);
    streaming = false;
    showNoFinger();
    return;
  }
  printStats();
  delay(POLL_INTERVAL_MS);
}

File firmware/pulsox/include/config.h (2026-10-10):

// Single place for every tunable of the PulsOx firmware: pins, sensor setup and
// the DSP parameters. The signal-processing values are starting points, meant
// to be adjusted against real captures (see tools/ppg_colab.ipynb).
#pragma once

// ---- Pins (PCB/Sensor_ctrl_pwr_pcb, "Esquematico V2") ----------------------
#define PIN_SDA_OX 3
#define PIN_SCL_OX 4
#define PIN_INT_OX 1   // MAX30102 INT, open-drain active low (not used yet: the FIFO is polled)

// ESP32-C3 Super Mini on-board LED, not wired to anything on the PCB (V2).
#define PIN_LED 8
#define LED_ON_LEVEL LOW   // active-low on the Super Mini; flip if it looks inverted
#define LED_PERIOD_IDLE_MS 125   // toggle period while the sensor is missing (fast blink)
#define LED_PERIOD_LIVE_MS 500   // toggle period while streaming (slow blink)

// ---- TFT orientation (lib/tft_st7735) -----------------------------------------
// The panel is mounted upside down, so the controller scans it rotated 180 degrees
// (rotation 2) and every screen is drawn as designed. The image origin in the
// controller RAM depends on the rotation: this module shows its window at column 0,
// row 32 in rotation 0 (offset -2, +29 from the library's 2, 3); in rotation 2 the
// library assumes column 2, row 1, so the same window needs -2, -1. If a noise strip
// shows up on one edge, nudge these (see lib/tft_st7735/tft_st7735.h, section 2.8).
#define TFT_ROTATION 2
#define TFT_X_ADJUST -2
#define TFT_Y_ADJUST -1

// ---- Status bar ---------------------------------------------------------------
// There is no battery measurement yet, and WiFi is not used: the bar shows this
// fixed battery level (a placeholder, NOT a reading) and the WiFi icon in grey.
#define BATTERY_PLACEHOLDER_PCT 100

// ---- Runtime ------------------------------------------------------------------
#define SERIAL_WAIT_MS 4000          // max wait for the monitor at boot (USB-CDC)
#define SERIAL_TX_TIMEOUT_MS 5       // longest a Serial write may wait for the host; never 0 (see serial_stream.cpp)
#define SENSOR_RETRY_MS 2000         // how often to retry while the sensor is missing
#define I2C_FAILS_BEFORE_LOST 10     // consecutive failed polls before declaring the sensor lost
#define STATS_PERIOD_MS 1000         // period of the summary line

// ---- MAX30102 setup ---------------------------------------------------------
// 400 sps with 4-sample averaging -> 100 samples/s. The 25 Hz of peripherals-test
// is too coarse to measure beat-to-beat intervals.
#define SENSOR_FS_HZ 100.0f
#define SENSOR_FIFO_CONFIG 0x50   // SMP_AVE=4, rollover on
#define SENSOR_SPO2_CONFIG 0x2F   // ADC_RGE=4096 nA, SR=400 sps, LED_PW=411 us (18 bit)
#define SENSOR_LED_RED_PA 0x24    // 36 * 0.2 mA ~ 7 mA
#define SENSOR_LED_IR_PA 0x24
#define SENSOR_ADC_MAX 262143.0f  // 2^18 - 1

#define I2C_CLOCK_HZ 400000
#define POLL_INTERVAL_MS 10       // the 32-sample FIFO holds 320 ms of data at 100 sps

// ---- Finger detection and saturation -----------------------------------------
#define FINGER_ON_IR_DC 50000.0f   // DC of IR above this -> finger present
#define FINGER_OFF_IR_DC 40000.0f  // ... and below this -> finger gone (hysteresis)
#define FINGER_DEBOUNCE_S 0.2f
#define SATURATION_FRACTION 0.95f  // raw sample above this fraction of full scale = saturated
#define SETTLE_S 2.0f              // after the finger appears: let the filters settle, no beats

// ---- Filtering -----------------------------------------------------------------
// The same Butterworth filters as tools/procesamiento.py, run in a single pass
// (the script uses filtfilt, which needs the whole recording). The device does not
// compute their coefficients: tools/gen_ppg_coefs.py reads these four values and
// the sample rate above, and writes lib/ppg/ppg_coefs.h. Run it again after
// changing any of them.
#define FILTER_ORDER 4             // order of each filter (the band-pass has twice the poles)
#define BAND_LOW_HZ 0.5f           // band-pass for the AC component
#define BAND_HIGH_HZ 4.0f
#define DC_CUTOFF_HZ 0.2f          // low-pass for the DC component

// A second, gentler band-pass only to DRAW the pulse on the TFT. The 0.5-4 Hz filter above
// is meant for measuring (RMS amplitude) and is too narrow to show the waveform: the
// dicrotic notch lives between 4 and 10 Hz. SpO2 and heart rate do not use this one.
#define VIEW_FILTER_ORDER 2
#define VIEW_BAND_LOW_HZ 0.5f
#define VIEW_BAND_HIGH_HZ 10.0f

// ---- Beat detection --------------------------------------------------------------
#define BEAT_ENV_TAU_S 2.0f        // decay of the peak envelope
#define BEAT_THRESHOLD_K 0.5f      // threshold = K * envelope
#define BEAT_MIN_AMP_PCT 0.01f     // ... but never below this % of the IR DC (rejects noise)
#define BEAT_REFRACTORY_S 0.3f
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

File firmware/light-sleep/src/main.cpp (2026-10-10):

// Light-sleep: low-power state for the PulsOx PCB (ESP32-C3 Super Mini + MAX30102).
//
// Runs once and never gets out of it:
//   1. MAX30102: LEDs to 0 mA + shutdown mode (~1 uA), read back to confirm.
//   2. ESP32-C3: LIGHT sleep with no wakeup source, so it stays asleep indefinitely.
//
// Nothing here ever turns the sensor back on. It is powered from the PCB's 3V3 rail,
// not by the ESP32, so it stays in shutdown while the board has power; only
// flashing another firmware (or a RESET, which just repeats step 1) changes that.
//
// The ESP32-C3's native USB-Serial-JTAG is clock-gated in light sleep: once asleep
// the PC sees the port drop and Serial is unusable. To flash again, hold BOOT
// (GPIO9), press RESET and release BOOT; right after a plain RESET the port is
// alive for ~5 s (BOOT_WINDOW) before it goes to sleep again.
#include <Arduino.h>
#include <Wire.h>
#include <esp_sleep.h>
#include "max30102.h"  // driver of firmware/pulsox/lib (lib_extra_dirs in platformio.ini)

#define PIN_SDA_OX 3
#define PIN_SCL_OX 4

#define SERIAL_WAIT_MS 4000   // max wait for the monitor at boot (on battery there's no host: times out)
#define SERIAL_GRACE_MS 1500  // after a reset USB re-enumerates and the monitor reconnects late
#define SHUTDOWN_TRIES 3
#define SHUTDOWN_RETRY_MS 100

static Max30102 sensor;

// begin() probes the sensor and soft-resets it (clears whatever LEDs/mode were left
// running); its result is not used because shutdown() is what has to succeed, and it
// reports the I2C error itself.
static bool shutdownSensor() {
  Wire.begin(PIN_SDA_OX, PIN_SCL_OX);
  Wire.setClock(100000);
  sensor.begin(Wire);
  for (uint8_t i = 0; i < SHUTDOWN_TRIES; i++) {
    if (sensor.shutdown()) return true;
    delay(SHUTDOWN_RETRY_MS);
  }
  return false;
}

void setup() {
  Serial.begin(115200);
  uint32_t start = millis();
  while (!Serial && millis() - start < SERIAL_WAIT_MS) delay(10);  // USB-CDC: wait for the monitor
  if (Serial) delay(SERIAL_GRACE_MS);

  Serial.println("=== light-sleep ===");
  if (shutdownSensor()) {
    Serial.println("MAX30102: LEDs a 0 mA y en shutdown (confirmado por lectura)");
  } else {
    Serial.printf("MAX30102: NO se pudo apagar, err=%u (%s). Reviso soldadura / SDA=GPIO3 SCL=GPIO4\n",
                  sensor.lastError(), Max30102::errorText(sensor.lastError()));
  }
  Wire.end();  // nobody talks to the sensor again

  Serial.println("ESP32-C3: light sleep indefinido (sin fuente de wakeup). El USB se corta.");
  Serial.flush();
}

void loop() {
  esp_sleep_disable_wakeup_source(ESP_SLEEP_WAKEUP_ALL);
  esp_light_sleep_start();  // no wakeup source: does not return. If it ever does, just sleep again.
}

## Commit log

2026-09-20 Add pulse-oximeter web dashboard, telemetry protocol, and design system
    No ESP32 firmware exists yet, so this defines the WebSocket JSON telemetry
    contract (PROTOCOL.md) the device will need to speak, and ships a complete
    mobile-first dashboard against it: large color-coded SpO2/BPM readouts
    (green/caution/danger, always icon+label, never color alone), live line
    charts with zone bands, a filterable history log, and a demo simulator so
    the app is fully testable before any hardware exists.
    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
2026-09-29 Se agrega modelo V1 de carcasa, test-placa, y diseño de PCB
    [Pulso oxímetro.3mf, Sensor_ctrl_pwr_pcb.kicad_pcb, Sensor_ctrl_pwr_pcb.kicad_sch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]
2026-10-02 Add:Tapa inferior para el cierre del pulsoximetro ; fix: Se cambiaron las tolerancias y distancias para que entren los componentes en la parte inferior
    [Pulso oxímetro.3mf, Tapa inferiOR.3mf]
2026-10-02 Add: firmware peripherals-test para validar MAX30102 y TFT ST7735S
    Firmware de bring-up (PlatformIO + Arduino, ESP32-C3 Super Mini) con el
    pinout del esquematico V2. Verifica scan I2C (0x57), PART_ID, temperatura
    del die, pin INT y readback del ST7735S por SPI; despues corre un patron
    visual en el TFT y deja una lectura IR/RED en vivo del MAX30102 (pantalla
    y Serial).
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2026-10-05 Arreglo de routeo de PCB con respecto al MOSFET PMOS
    [Sensor_ctrl_pwr_pcb.kicad_pcb]
2026-10-05 feat:Se agregó una posibilidad de test de MAX30102 en el sketch de batter-test ; fix: Ahora apaga los LEDS (corriente 0 mA) y deja en modo shutdown el sensor
    [main.cpp]
2026-10-05 Redesign web UI: bottom nav, live PPG trace, per-measurement history
    - Three views (Historial / Dashboard / Ajustes) switched by a fixed bottom
    navigation bar (hash routes). Light theme is now the default.
    - Consumer-wearable look: SpO2 gauge ring, heart-rate card, status always
    shown with icon + text; new tokens (blue = SpO2, violet = HR/PPG).
    - Dashboard idles until the device's measurement-start packet arrives, then
    shows readings, a stopwatch and a live filtered PPG trace (canvas, 6 s
    sliding window) under the heart rate.
    - History moves to its own view: trend chart with SpO2/HR tabs and readings
    grouped by measurement (v1 history is migrated under "Lecturas anteriores").
    - Sim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
2026-10-06 feat: firmware PulsOx con adquisicion cruda del MAX30102 y tools/capture.py
    Arranca el sensor a 100 muestras/s (LEDs ~7 mA), imprime un resumen por
    segundo y, en modo CSV (comando 'c'), transmite cada muestra cruda.
    tools/capture.py graba el stream a CSV (muestras, resultados y eventos) y
    reporta huecos de muestras. Incluye una captura de ejemplo con el dedo puesto.
    [20261006_190958_dedo_quieto.csv, 20261006_190958_dedo_quieto_events.csv]
2026-10-07 carga de las primeras 5 muestras
    [20261006_190601_dedo_quieto.csv, 20261006_202329_10mA_events.csv, 20261006_211217_7mA_events.csv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]
2026-10-07 Carga de mediciones de pulsoximetro Tomy
    [Muestra_tomy_pulgar.csv, muestra_tomy_indice.csv]
2026-10-07 nueva muestra de pulgar
    [Muestra_tomy_pulgar_v2.csv]
2026-10-07 Nueva medicion de pulgar con pulsoximetro
    [pulgar_tomy_v3.csv]
2026-10-07 Nueva medicion comparada con reloj Samsung
    [pulgar_V4.csv]
2026-10-07 Se agregó la libreria y configuración de la Pantalla TFT. Adaptado a los margenes y los pines que fueron asignados al esp32
2026-10-07 feat:Diseño de pantallas gráficas TFT para la interfaz de usuario en los distintos casos de medicion y errores. Por testear
    [gen_display_assets.py]
2026-10-07 feat(web): fuente "Nube" (CloudSource + CloudHistory) con tests de Node
    CloudSource lee devices/<id>/live.json por EventSource (Firebase REST streaming),
    aplica los eventos put/patch y sintetiza los mismos frames que el WebSocket
    (hello, measurement_start, telemetry, ppg, measurement_end), con watchdog de 10 s
    y reconexion. CloudHistory expone la interfaz de HistoryStore leyendo
    sessions.json y recalculando el estado con los umbrales del visor.
    cloud-config.js queda con databaseURL vacio: la fuente Nube no se ofrece.
    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
2026-10-07 fix(web): la fuente Nube no cree un `live` residual al conectar
    Si el dispositivo se apaga a mitad de una medicion (bateria agotada) el nodo
    `live` queda en la base. Un visor que se conecta despues veia una medicion
    fantasma durante 10 s. Ahora un `live` presente en el valor inicial del stream
    solo se anuncia si cambia (llega otro seq) dentro de 3 s; si no, se ignora.
    Un `live` que aparece con el stream ya abierto arranca sin espera.
2026-10-07 feat(web): integrar la fuente Nube en la app
    - Selector de fuente en Ajustes > Conexion (Nube / Red local / Demo), persistido
    en pulsox.source con migracion de wsUrl/demoMode. La opcion Nube solo aparece
    si cloud-config.js tiene databaseURL; arranque por defecto en Nube.
    - ConnectionManager.connectCloud(): tercera fuente con el mismo contrato
    onFrame/onState. connectTo() ahora cierra el socket previo.
    - app.js: history intercambiable (local vs CloudHistory), beginSession acepta
    id/started_at del frame (cronometro correcto para quien se une a mitad),
    hello puede traer battery_pct, textos de estado segun la fuente, borrado del
    historial deshabilitado en Nube.
    - ppg.js: setRenderDel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
2026-10-07 feat(tools): reglas de Firebase, dispositivo simulado y verificador de reglas
    - database.rules.json: lectura publica de devices/<id>, escritura solo para el
    uid del dispositivo (placeholder REEMPLAZAR_UID_DEL_DISPOSITIVO), .validate de
    rangos y formas, .indexOn startedAt en sessions.
    - fake_device.py (solo stdlib): login REST, renovacion del token, PUT info/live
    a 1 Hz con PPG sintetico, POST readings, PATCH sessions, DELETE live al
    terminar; --crash simula un corte de energia. Es la especificacion ejecutable
    del cliente del ESP32.
    - check_rules.py: comprueba contra el servicio real que la lectura anonima anda,
    que la escritura anonima / de otro usuario se deniega y que .validate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
2026-10-07 test(tools): mock local de Firebase RTDB + Auth y prueba con EventSource real
    mock_rtdb.js emula la API REST de la Realtime Database (put/patch/post/delete,
    {".sv":"timestamp"}, orderBy+limitToLast, streaming SSE con keep-alive, CORS y
    redireccion 307 opcional) y los endpoints de Auth que usan fake_device.py y
    check_rules.py. El control de acceso sale de database.rules.json (evaluador de
    un subconjunto de las reglas). Permite probar todo el camino sin proyecto
    Firebase; no reemplaza la verificacion contra el servicio real.
    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
2026-10-07 docs: transporte en la nube (PROTOCOL.md) y configuracion de Firebase (README)
    PROTOCOL.md: nueva seccion "Transporte en la nube" con el modelo de datos
    (info / live / sessions), la tabla de llamadas REST del dispositivo (login,
    renovacion del token, PUT/POST/PATCH/DELETE y su orden de cierre), keep-alive,
    arranque y deep sleep, y como la web sintetiza los frames del protocolo.
    README.md: pasos para crear el proyecto Firebase, pegar las reglas, cargar las
    credenciales en tools/cloud/.env, verificar con check_rules.py y probar con
    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
2026-10-07 config: databaseURL y UID del dispositivo del proyecto Firebase pulsoximetro-esp
    Reglas verificadas contra el servicio real con tools/cloud/check_rules.py (18/18).
2026-10-08 feat: Rotación de 180° de la pantalla TFT
    El módulo queda montado al revés, así que el controlador escanea la imagen en rotación 2 (TFT_ROTATION) y las pantallas se ven como en el diseño. El origen de la imagen en la RAM del controlador depe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
2026-10-08 fix(web): preparar el despliegue en GitHub Pages
    - app: ocultar la fuente "Red local" cuando la pagina se abre por https
    (el navegador bloquea ws://); un perfil guardado con "local" cae a Nube.
    - sw: network-first con la cache solo como respaldo sin red, para que cada
    deploy se vea en la siguiente carga sin subir CACHE_NAME a mano (v5); la
    instalacion saltea la cache HTTP de Pages (max-age=600).
    - manifest: id relativo ("./") en lugar de una ruta que no coincide con el
    nombre del repo.
    - workflow: correr node --test antes de subir el artefacto, para no
    desplegar con tests rotos.
2026-10-08 docs(firmware): plan del sketch de prueba cloud-test (ESP32-C3 -> Firebase)
    Plan aprobado, todavia sin implementar: WiFi + TLS con CAs raiz de Google +
    login/refresh de token + medicion simulada hacia la Realtime Database,
    portando tools/cloud/fake_device.py. Pensado para retomarlo desde otra
    sesion sin el contexto de la conversacion original.
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2026-10-10 feat(firmware): boton de wakeup en GPIO0 y deep sleep (etapa 1)
    El firmware de pulsox pasa a vivir dormido: ESP32 en deep sleep, MAX30102 en
    shutdown y TFT en sleep-in con el backlight apagado. El boton (GPIO0, activo en
    bajo) lo despierta.
    - button: antirrebote por software (30 ms), ignora la pulsacion que desperto al
    chip hasta que se suelta, comando serie 'b' para simular una pulsacion.
    GPIO0 es entrada sin pull-up interno: el de la placa del boton ya existe y el
    interno forma un divisor con la resistencia serie (R5) que impide llegar a un
    nivel bajo.
    - power: causa del wakeup, retencion de pines (backlight, CS, RESET, LED) en
    deep sleep y wakeup por nivel bajo de GPIO0. Si el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
    [config.h, main.cpp, serial_stream.cpp]
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2026-10-10 feat(firmware): pantallas de conectando, esperar dedo, progreso y resultado (etapa 3)
    Cuatro pantallas nuevas con la paleta, las fuentes y el estilo del diseno:
    - Conectando: el icono grande de WiFi prende sus arcos de a uno.
    - Coloca el dedo: el sensor y el arco animado de la pantalla de error, sin la
    cruz roja, para el tramo entre conectar y detectar el dedo.
    - Progreso: barra fina bajo el banner de la pantalla de medicion.
    - Resultado: la pantalla de medicion congelada (valores, ultima traza, corazon
    quieto) con "COMPLETADO" en el banner, o el banner de alerta si el nivel no es
    normal, y en la barra superior "ENVIADO" / "NO ENVIADO" con el icono de WiFi
    azul o gris. Si la etiquet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
    [gen_display_assets.py]
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2026-10-10 feat(firmware): maquina de estados completa del dispositivo (etapa 5)
    app.cpp reemplaza el flujo provisorio de main.cpp (que queda en setup/loop):
    boton -> CONECTANDO -> ESPERA_DEDO -> MIDIENDO -> CERRANDO -> RESULTADO
    \-> CERRANDO -> ERROR
    RESULTADO / ERROR: 2 minutos en pantalla y deep sleep; el boton mide de nuevo.
    - El sensor arranca recien al esperar el dedo, no mientras conecta: se ahorran
    ~6 s de LEDs encendidos por medicion.
    - Mientras mide el boton se ignora. ppg_session (etapa 4) decide cada segundo si
    termina (resultado = mediana de los segundos estables) o se descarta (dedo
    retirado, senal erratica, lecturas insuficientes,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
    [config.h, main.cpp]
2026-10-10 fix(firmware): una muestra basura del I2C ya no invalida la medicion
    Sintoma: a veces, en plena medicion, la senal pulsatil se aplanaba, volvia una
    "continua" y SpO2 / BPM tardaban en estabilizarse de nuevo.
    Causa: el MAX30102 entrega a veces una muestra con los seis bytes en 0xFF (un
    glitch del bus), que enmascarada a 18 bits es 262143 en los dos canales en medio
    de una senal de ~90000. El pipeline la toma por saturacion: salto enorme en los
    filtros, el filtro de dibujo rebota y estira la escala automatica hasta que el
    pulso parece una linea plana, y SpO2 queda invalido los 10 s que la saturacion
    permanece en la ventana. En los logs: SATURADO con el valor crudo en ~91000, en 2
    de las 7 med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
    [config.h, serial_stream.cpp]
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2026-10-11 fix(firmware): la traza ya no se aplana tras un golpe en la senal
    La traza de la pantalla se autoescalaba al min/max de su ventana (2,5 s). Un
    glitch o un movimiento mete un pico de miles de cuentas en una onda de cientos
    y la escala se abria para que entrara: la onda real quedaba como una linea
    plana hasta que el pico salia de la ventana, con SpO2 y BPM todavia validos.
    Ahora la escala es la mediana de los ultimos 5 s (span y punto medio de cada
    segundo, src/trace_scale.c), con 15 % de margen. Un pico se dibuja recortado
    contra el borde del grafico en vez de achicar la onda. No se toca lib/ppg.
    Medido sobre las capturas con tools/trace_host.c (nuevo, compara antes y
    ahora): el glitch real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
2026-10-11 feat(firmware): filtros pasabanda de medicion y pantalla en 0,5-6 Hz de orden 4
    Los dos pasabanda quedan iguales: el de la medicion (BAND_*) pasa de 0,5-4 Hz a
    0,5-6 Hz y el de la pantalla (VIEW_*) de 0,5-10 Hz orden 2 a 0,5-6 Hz orden 4.
    Solo cambian BAND_HIGH_HZ (4 -> 6), VIEW_FILTER_ORDER (2 -> 4) y
    VIEW_BAND_HIGH_HZ (10 -> 6); el pasabajos de DC de 0,2 Hz y el resto de los
    parametros siguen igual. ppg_coefs.h se regenero con tools/gen_ppg_coefs.py y
    se corrigieron los comentarios que describian el filtro de pantalla como mas
    ancho que el de medicion.
    Medido sobre las 10 capturas: validate_ppg.py da todo OK (el pipeline en C
    coincide con scipy); ningun veredicto de sesion cambia, SpO2 ig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
2026-10-12 feat(firmware): filtros de medicion y de pantalla de orden 2
    FILTER_ORDER y VIEW_FILTER_ORDER pasan de 4 a 2 en config.h. ppg_coefs.h se
    regenero con tools/gen_ppg_coefs.py. FILTER_ORDER tambien fija el orden del
    pasabajos de DC (0,2 Hz), que pasa a orden 2.
    Por que: con orden 4 el pasabanda 0,5-6 Hz tiene 8 polos y un retardo de grupo
    muy desparejo. La traza pierde la subida rapida y la muesca dicrotica aparece
    como un hombro antes del pico. Con la misma respuesta en amplitud y fase cero la
    forma vuelve a ser la de manual, asi que es un problema de fase, no de banda.
    Con orden 2 la subida vuelve a ser mas rapida que la bajada; en la placa se ve
    mejor.
    Efecto en la medicion (replica en Pyt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
2026-11-13 docs(firmware): comentado de código
    Bloque de documentación en español arriba de cada función de
    firmware/pulsox (src, lib y test), con @brief, @details, @param y
    @peripherals. Solo comentarios: el código no cambia.
    También se corrigen los comentarios que hablaban de 100 muestras/s y
    320 ms de FIFO: el sensor entrega 50 muestras/s (400 sps promediadas
    de a 8) y el FIFO guarda 640 ms.
